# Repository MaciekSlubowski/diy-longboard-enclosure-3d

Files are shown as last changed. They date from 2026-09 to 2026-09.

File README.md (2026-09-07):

# Electric Longboard Battery Enclosure

Parametric OpenSCAD script generating a segmented battery enclosure for DIY electric skateboards. The model is divided into interlocking sections using Z-staggered joints to allow printing on standard desktop 3D printers.


*Fully assembled board with the printed enclosure.*

<p align="center">
  
  
</p>

<p align="center"><em>Printed segments connected together on the workbench.</em></p>

<p align="center">
  
  
</p>

<p align="center"><em>Detail of a single printed enclosure segment showing the Z-joint.</em></p>

## Print Bed Requirements

To print the default configuration, your 3D printer must have a minimum build volume of **220 x 220 mm** (compatible with standard machines like the Creality Ender 3). 

The OpenSCAD script calculates the total length of the model (`straight_length` + 2 * `taper_length`) and divides it into 4 equal segments. With the default 740 mm total length, each sliced segment is exactly 185 mm long and up to 220 mm wide.

## Customization Variables

Open the `.scad` file in OpenSCAD to modify the enclosure parameters.

### Main Dimensions
* `straight_length` (Default: 600) - Length of the central straight section (mm). Do not change this value if you need backward compatibility with previously printed segments.
* `right_side_offset` (Default: 40) - Shifts the right wall inward to shorten the final segment without altering the joint coordinates of the remaining parts.
* `total_width` (Default: 220) - Maximum width at the center (mm).
* `end_width` (Default: 160) - Width at the nose and tail sections (mm).
* `outer_height` (Default: 50) - Total depth of the enclosure (mm).

### Walls and Hardware
* `flange_width` (Default: 5) - Width of the top lip contacting the deck.
* `wall_thickness` (Default: 4) - Enclosure shell thickness.
* `screws_per_side` (Default: 6) - Number of mounting holes distributed along one side wall.
* `inner_hole_diameter` (Default: 4) - Diameter for mounting screws (e.g., 4mm for M4).
* `counterbore_diameter` / `counterbore_depth` - Dimensions for recessed screw heads.
* `additional_mounts` - Array for custom internal pillars format: `[X, Y, Rotation]`.

### ESC Heatsink Cutout
* `cutout_length` & `cutout_width` - Dimensions of the heatsink window.
* `cutout_X` & `cutout_Y` - Coordinates of the cutout on the enclosure floor.

### Tolerances
* `print_clearance` (Default: 0.1) - Gap between the interlocking teeth. Default is 0.1 mm. Increase to 0.15 mm or 0.2 mm if the printed joints are too tight.

## Generating STL Files

Change the `part_to_print` variable in the script, render (F6), and export to STL:

* `part_to_print = 0;` - Renders the full uncut enclosure.
* `part_to_print = 1;` - Renders Part 1 (Left end / Nose).
* `part_to_print = 2;` - Renders Part 2 (Middle-left).
* `part_to_print = 3;` - Renders Part 3 (Middle-right).
* `part_to_print = 4;` - Renders Part 4 (Right end / Tail).

This project is open-source and provided strictly for personal, educational, and non-commercial purposes. You are free to explore, modify, and learn from the codebase. **If you wish to use this project for commercial purposes, please contact me.**

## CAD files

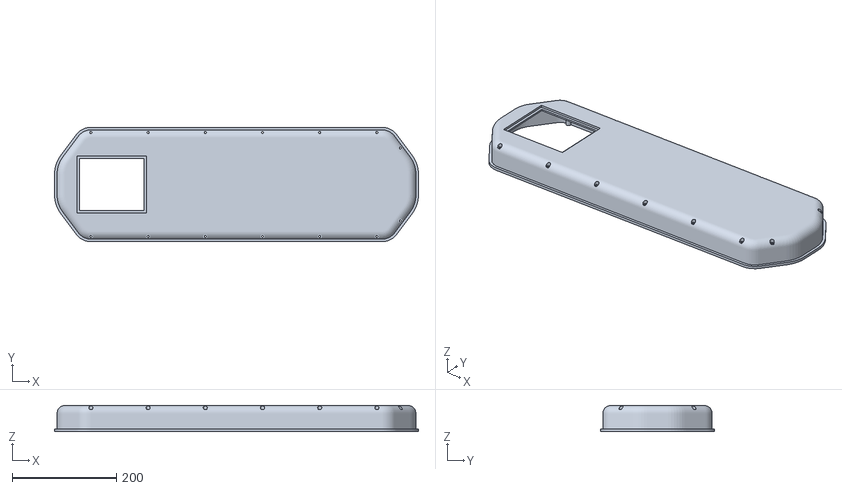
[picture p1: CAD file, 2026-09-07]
Full uncut model.stl
700.0 x 220.0 x 50.1

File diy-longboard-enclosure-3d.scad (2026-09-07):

// ============================================================================
// BATTERY ENCLOSURE - 3D INTERLOCKING SYSTEM
// Features: Internal Mesh Welding, Z-Staggering Joints, Render Caching
// ============================================================================

// Global resolution for curved surfaces (higher = smoother, but slower rendering)
$fn = 60; 

// --- 1. MAIN DIMENSIONS & SHAPE PARAMETERS ---
// NOTE: Do not change 'straight_length' to maintain full compatibility with printed parts 1, 2, and 3!
straight_length = 600;      // Length of the central straight section [mm]
taper_length = 70;          // Length of the angled/tapered sections at both ends [mm]
total_width = 220;          // Maximum width of the enclosure at the center [mm]
end_width = 160;            // Width of the enclosure at the very ends (nose/tail) [mm]
outer_height = 50;          // Total outer height/depth of the enclosure [mm]

// 🔥 NEW PARAMETER: Shifts the right wall inward without breaking the rest of the model.
// Useful if you need to slightly shorten the total length on one side for a specific deck.
right_side_offset = 40; 

// --- WALLS & FLANGES ---
flange_width = 5;           // Width of the top lip/flange used to seal against the deck [mm]
flange_thickness = 5;       // Thickness (Z-height) of the top lip [mm]
wall_thickness = 4;         // General thickness of the enclosure walls and bottom [mm]

// --- RADII & FILLETS ---
outer_radius = 35;          // Corner radius for the central straight section [mm]
end_radius = 60;            // Corner radius for the nose/tail tips [mm]
bottom_fillet_radius = 15;  // Rounding radius connecting the side walls to the bottom floor [mm]

// --- HEAT SINK CUTOUT PARAMETERS (e.g. for ESC cooling) ---
cutout_length = 134;        // Length of the rectangular cutout for the heat sink [mm]
cutout_width = 110;         // Width of the rectangular cutout [mm]
cutout_X = -260;            // X-axis position of the cutout (negative values move it towards the left)
cutout_Y = 0;               // Y-axis position (0 = centered)

// --- 2. INTERNAL SCREW MOUNTS & STANDOFFS ---

// Note: 'screw_positions_X' is a legacy reference array. 
// The actual placement of side screws is dynamically calculated via the 'screws_per_side' loop below.
screw_positions_X = [-200, -100, 0, 100, 200]; 

// Additional custom standoffs (e.g., for mounting the BMS, ESC, or battery straps)
// Format: [X_position, Y_position, Rotation_angle, Z_unused]
additional_mounts = [  
    // Rear pillars are shifted left by 'right_side_offset' to stay inside the shortened wall
    [335 - right_side_offset, 70, 90, 100],    
    [335 - right_side_offset, -70, -90, -100]  
];

// --- HARDWARE SPECS (Screws / Threaded Inserts) ---
mount_radius = 5;           // Outer radius of the plastic pillar holding the screw [mm] (Diameter = 10mm)
inner_hole_diameter = 4;    // Diameter of the through-hole (e.g., 4mm for M4 screws or heat-set inserts)
counterbore_diameter = 8;   // Diameter of the recessed hole for the screw head [mm]
counterbore_depth = 8;      // Depth of the recess for the screw head [mm]

// --- SIDE WALL MOUNTING HOLES DISTRIBUTION ---
screws_per_side = 6;        // Number of mounting holes distributed evenly along ONE side wall (total = 12)
x_start_screw = -straight_length / 2;     // X-coordinate of the first screw (start of the straight section)
x_end_screw = straight_length / 2 - 50;   // X-coordinate of the last screw (end of the straight section minus offset)
screw_step = (x_end_screw - x_start_screw) / (screws_per_side - 1); // Auto-calculated distance between screws

// --- 3. PRINT & SLICE SETTINGS ---
// Select which part of the enclosure to render for exporting to STL.
// 0 = Full uncut model (for preview or large printers)
// 1 = Part 1 (Left end / Nose)
// 2 = Part 2 (Middle-left segment)
// 3 = Part 3 (Middle-right segment)
// 4 = Part 4 (Right end / Tail - currently shortened by 'right_side_offset')
part_to_print = 0; 

// Tolerance gap between the interlocking joints.
// 0.1mm is tight and good for well-calibrated printers.
// Increase to 0.15 or 0.2 if the parts don't fit together after printing.
print_clearance = 0.1;   

// ============================================================================
// CORE ENCLOSURE LOGIC & SHAPES (Do not edit below unless modifying the logic)
// ============================================================================

total_length = straight_length + (2 * taper_length);
segment_length = total_length / 4;

x_mid = straight_length / 2;
x_end = (straight_length / 2) + taper_length - end_radius;
y_max = (total_width / 2) - outer_radius;
y_end = (end_width / 2) - end_radius;

// Base profile of the enclosure
module base_profile(h, r_mid, r_end) {
    hull() {
        // 🔥 RIGHT SIDE (Shortened by right_side_offset)
        translate([ x_end - right_side_offset,  y_end, 0]) cylinder(r=max(0.1, r_end), h=h);
        translate([ x_end - right_side_offset, -y_end, 0]) cylinder(r=max(0.1, r_end), h=h);
        translate([ x_mid - right_side_offset,  y_max, 0]) cylinder(r=max(0.1, r_mid), h=h);
        translate([ x_mid - right_side_offset, -y_max, 0]) cylinder(r=max(0.1, r_mid), h=h);
        
        // 🔥 LEFT SIDE (Remains in original positions, keeping backwards compatibility)
        translate([-x_mid,  y_max, 0]) cylinder(r=max(0.1, r_mid), h=h);
        translate([-x_mid, -y_max, 0]) cylinder(r=max(0.1, r_mid), h=h);
        translate([-x_end,  y_end, 0]) cylinder(r=max(0.1, r_end), h=h);
        translate([-x_end, -y_end, 0]) cylinder(r=max(0.1, r_end), h=h);
    }
}

module solid_3d(delta) { 
    base_profile(0.1, outer_radius - delta, end_radius - delta); 
}

// Generates the outer shell with bottom fillets
module outer_shell() {
    union() {
        base_profile(flange_thickness, outer_radius, end_radius);
        hull() {
            translate([0, 0, 0]) solid_3d(flange_width);
            translate([0, 0, outer_height - bottom_fillet_radius]) solid_3d(flange_width);
            for (a = [10 : 10 : 90]) {
                dz = bottom_fillet_radius * sin(a);
                dinset = bottom_fillet_radius * (1 - cos(a));
                translate([0, 0, outer_height - bottom_fillet_radius + dz])
                    solid_3d(flange_width + dinset);
            }
        }
    }
}

// Generates the internal cavity to hollow out the enclosure
module internal_cavity() {
    hull() {
        r_inner = max(0.1, bottom_fillet_radius - wall_thickness);
        z_start_inner = outer_height - wall_thickness - r_inner + 0.011;
        
        translate([0, 0, -1]) solid_3d(flange_width + wall_thickness);
        translate([0, 0, z_start_inner]) solid_3d(flange_width + wall_thickness);
        
        for (a = [10 : 10 : 90]) {
            dz_inner = r_inner * sin(a);
            dinset_inner = r_inner * (1 - cos(a));
            translate([0, 0, z_start_inner + dz_inner])
                solid_3d(flange_width + wall_thickness + dinset_inner);
        }
    }
}

// Shell base for boolean operations in the interlocking joint system
module shell_base(offset_th) {
    th = (wall_thickness / 2) + offset_th;
    th_z = (wall_thickness / 2);
    r_mid = max(0.1, bottom_fillet_radius - th_z);
    z_start = outer_height - th_z - r_mid + 0.022 + (offset_th * 0.005); 

    hull() {
        translate([0, 0, -1]) solid_3d(flange_width + th);
        translate([0, 0, z_start]) solid_3d(flange_width + th);
        for (a = [10 : 10 : 90]) {
            dz = r_mid * sin(a);
            dinset = r_mid * (1 - cos(a));
            translate([0, 0, z_start + dz])
                solid_3d(flange_width + th + dinset);
        }
    }
}

// Hardware cutouts and internal structural reinforcements
module rectangular_cutout() {
    translate([cutout_X, cutout_Y, 40]) 
    cube([cutout_length, cutout_width, 60], center=true);
}

module inner_band() {
    delta_band_outer = flange_width + 1.0; 
    delta_band_inner = flange_width + wall_thickness - 1.0; 
    
    translate([0, 0, 34]) difference() {
        base_profile(2, outer_radius - delta_band_outer, end_radius - delta_band_outer);
        translate([0, 0, -1]) base_profile(4, outer_radius - delta_band_inner, end_radius - delta_band_inner);
    }
}

module heatsink_flange() {
    z_inner = outer_height - wall_thickness;
    thickness = 3;
    outer_len = cutout_length + 10;
    outer_wid = cutout_width + 10;
    inner_len = cutout_length - 10;
    inner_wid = cutout_width - 10;

    translate([cutout_X, cutout_Y, z_inner - (thickness / 2) + 0.01])
    difference() {
        cube([outer_len, outer_wid, thickness], center=true);
        cube([inner_len, inner_wid, thickness + 1], center=true);
    }
}

// ============================================================================
// MOUNTING SYSTEM (Pillars & Holes)
// ============================================================================
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
